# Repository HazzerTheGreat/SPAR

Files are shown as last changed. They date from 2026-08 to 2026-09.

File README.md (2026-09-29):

# SPAR

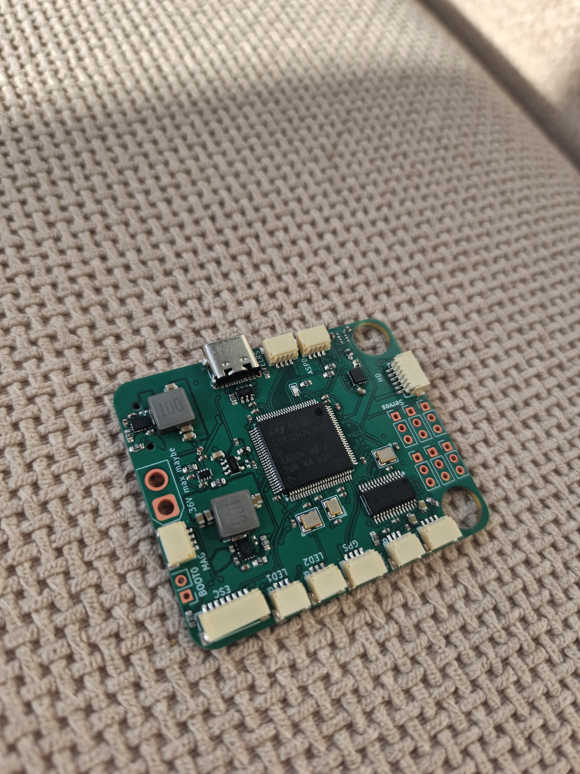
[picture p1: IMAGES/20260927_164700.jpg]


This is a flight controller primarily designed for fixed wing aircraft (or quadcopters etc) that is designed to 
run either BetaFlight, INAV or ArduPilot firmware. It handles flight stabilization, OSD, control of servos, waypoints,
data logging and anything else any other flight controller can do. This flight controller has an STM32H743 which is 
an extremely capable MCU with a blazing fast speed of up to 480MHz. Most likely overkill for the majority of applications
but it can accomodate for the most demanding projects. I made it as I was interested in the design of such systems
and also enjoy building aircraft and could find a highly capable flight controller useful plus the benefit that I have
built it myself.

**Specs:**

- ICM-42688-P for peak performance and high resolution positional sensing
- STM32H743 for processing whatever you need
- 5V and 9V buck converters for handling high power peripherals
- Micro SD card for black box logging
- 4 in 1 ESC support with DSHOT
- 6 other PWM outputs
- Analog OSD through AT7456E
- Support for external magnetometer, airspeed sensor and GPS
- BMP280 barometer for altitude measurements

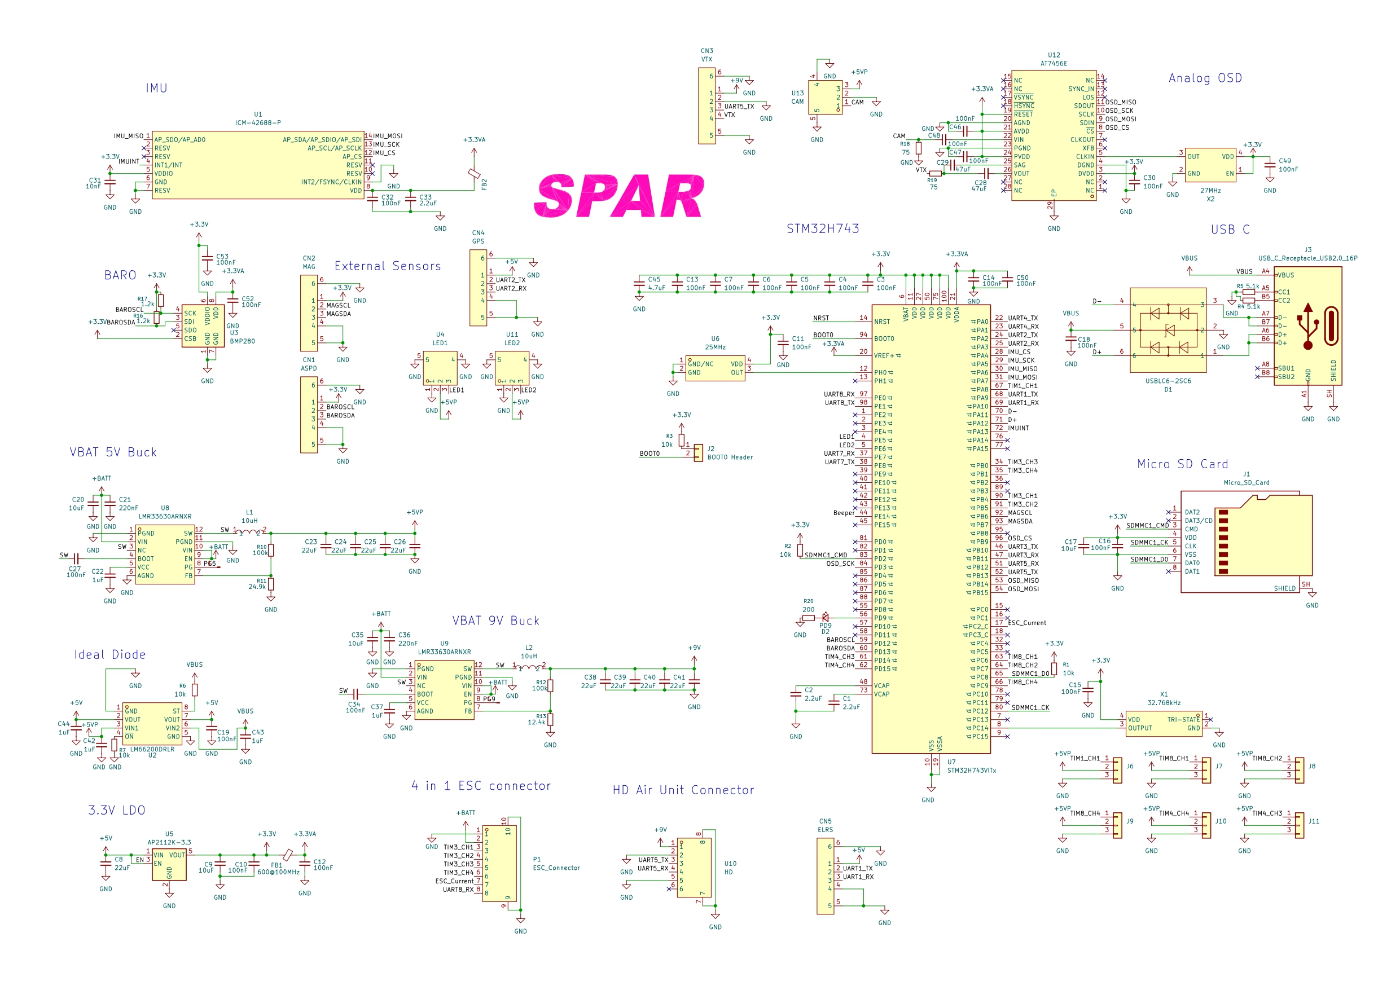
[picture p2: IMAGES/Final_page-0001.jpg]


**Peripherals:**

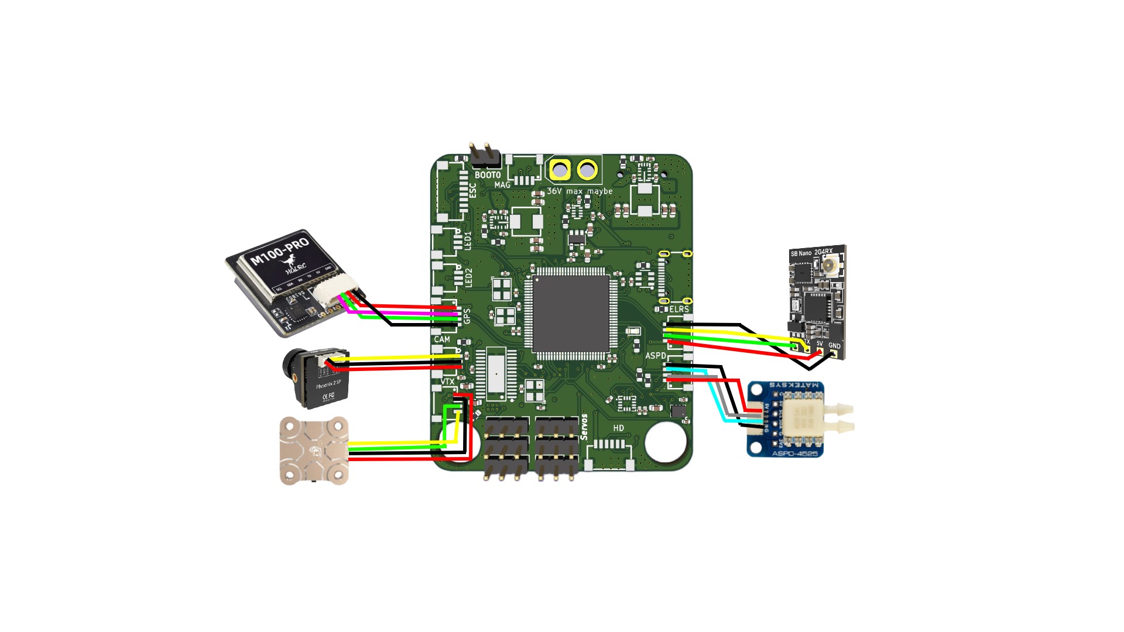
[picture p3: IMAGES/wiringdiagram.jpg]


The flight controller board has connectors for external airspeed, GPS, and mag sensors as well as plugs for ELRS, 4 in 1 ESC, analog camera, analog VTX, digital VTX and PWM LEDs.

**Firmware/flashing:**

This board does not have custom firmware, it is based on INAV: https://github.com/iNavFlight/inav/.
However a custom build of INAV including relevant target configuration is required.
I will put this custom target in the /Project_Files/INAV folder. This tutorial shows how to build INAV with a custom target: https://youtu.be/ThrsS_y9zDo?si=cllAaaTRHZ6ADbW4
To flash the board, the board must be powered up with the boot0 pin shorted to enter DFU mode on the STM32 where it can then be flashed in INAV configurator.

**BOM:**

The board costs about £27 from JLCPCB for a basic 6 layer PCB. The BOM for components can be found in the BOM.csv in the production folder. This totals around £40 which mainly
accounts for buying large quantities of passives so the per board price is probably much cheaper.

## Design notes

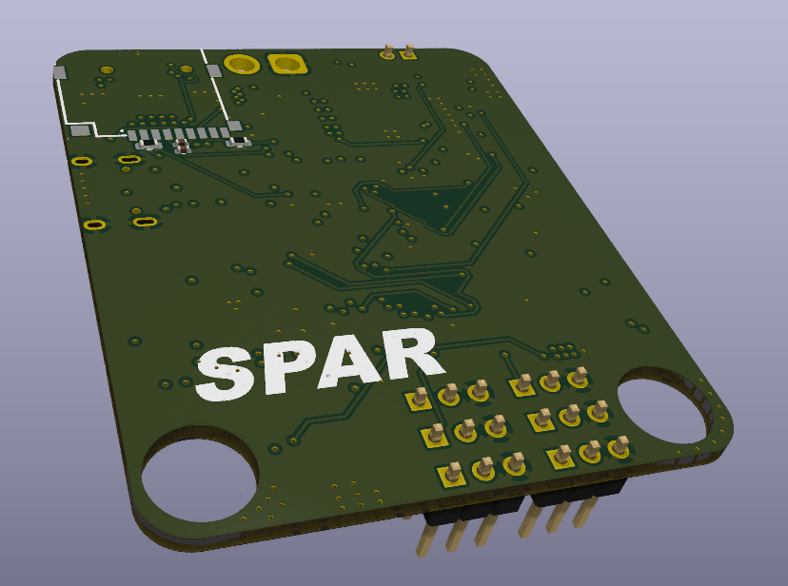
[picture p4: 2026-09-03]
IMAGES/pcb7.png

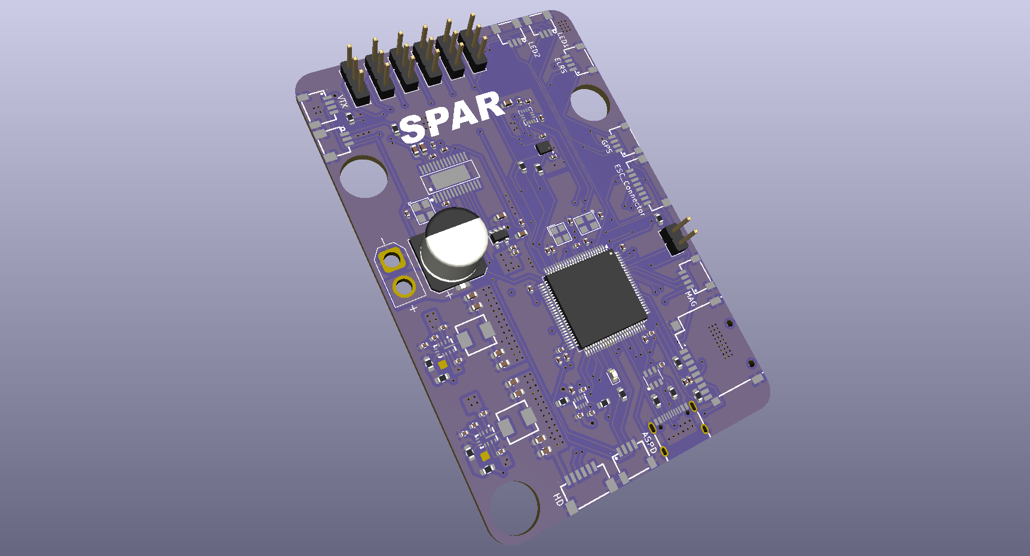
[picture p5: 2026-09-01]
IMAGES/FlightController.png

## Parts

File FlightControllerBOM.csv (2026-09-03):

Reference | Qty | Value | DNP | Exclude from BOM | Exclude from Board | Exclude from Simulation | Exclude from Position Files | Footprint | Datasheet | Price (minimum order):
C1,C2,C33 | 3 | 2.2uF |  |  |  |  | ${EXCLUDE_FROM_POS_FILES} | Capacitor_SMD:C_0402_1005Metric |  |  | 0.45
C3,C4,C5,C6,C7,C10,C11,C12,C13,C14,C15,C16,C18,C19,C27,C30,C32,C34,C46,C47,C48,C49,C50,C52,C53 | 25 | 100nF |  |  |  |  | ${EXCLUDE_FROM_POS_FILES} | Capacitor_SMD:C_0402_1005Metric |  |  | 0.45
C8,C23,C24,C25,C26,C38,C39,C40,C41 | 9 | 22uF |  |  |  |  | ${EXCLUDE_FROM_POS_FILES} | Capacitor_SMD:C_0603_1608Metric |  |  | 0.45
C9,C17,C20,C35 | 4 | 10uF |  |  |  |  | ${EXCLUDE_FROM_POS_FILES} | Capacitor_SMD:C_0402_1005Metric |  |  | 0.45
C21,C36 | 2 | 220nF |  |  |  |  | ${EXCLUDE_FROM_POS_FILES} | Capacitor_SMD:C_0402_1005Metric |  |  | 0.45
C22,C37,C42,C43,C44 | 5 | 1uF |  |  |  |  | ${EXCLUDE_FROM_POS_FILES} | Capacitor_SMD:C_0402_1005Metric |  |  | 0.45
C28,C29 | 2 | 47uF |  |  |  |  | ${EXCLUDE_FROM_POS_FILES} | Capacitor_SMD:C_0603_1608Metric |  |  | 0.97
C31 | 1 | 10nF |  |  |  |  | ${EXCLUDE_FROM_POS_FILES} | Capacitor_SMD:C_0402_1005Metric |  |  | 0.45
C45 | 1 | 4.7uF |  |  |  |  | ${EXCLUDE_FROM_POS_FILES} | Capacitor_SMD:C_0402_1005Metric |  |  | 0.45
CN1 | 1 | ASPD |  |  |  |  | ${EXCLUDE_FROM_POS_FILES} | easyeda2kicad:CONN-SMD_4P-P1.00_SM04B-SRSS-TB-LF-SN | https://lcsc.com/product-detail/Others_JST-Sales-America__JST-Sales-America-SM04B-SRSS-TB-LF-SN_C160404.html |  | 0.18
CN2 | 1 | MAG |  |  |  |  | ${EXCLUDE_FROM_POS_FILES} | easyeda2kicad:CONN-SMD_4P-P1.00_SM04B-SRSS-TB-LF-SN | https://lcsc.com/product-detail/Others_JST-Sales-America__JST-Sales-America-SM04B-SRSS-TB-LF-SN_C160404.html |  | 0.19
CN3 | 1 | VTX |  |  |  |  | ${EXCLUDE_FROM_POS_FILES} | easyeda2kicad:CONN-SMD_4P-P1.00_SM04B-SRSS-TB-LF-SN | https://lcsc.com/product-detail/Others_JST-Sales-America__JST-Sales-America-SM04B-SRSS-TB-LF-SN_C160404.html |  | 0.18
CN4 | 1 | GPS |  |  |  |  | ${EXCLUDE_FROM_POS_FILES} | easyeda2kicad:CONN-SMD_4P-P1.00_SM04B-SRSS-TB-LF-SN | https://lcsc.com/product-detail/Others_JST-Sales-America__JST-Sales-America-SM04B-SRSS-TB-LF-SN_C160404.html |  | 0.18
CN5 | 1 | ELRS |  |  |  |  | ${EXCLUDE_FROM_POS_FILES} | easyeda2kicad:CONN-SMD_4P-P1.00_SM04B-SRSS-TB-LF-SN | https://lcsc.com/product-detail/Others_JST-Sales-America__JST-Sales-America-SM04B-SRSS-TB-LF-SN_C160404.html |  | 0.18
D1 | 1 | USBLC6-2SC6 |  |  |  |  | ${EXCLUDE_FROM_POS_FILES} | easyeda2kicad:SOT-23-6_L2.9-W1.6-P0.95-LS2.8-BL | https://lcsc.com/product-detail/Diodes-ESD_STMicroelectronics_USBLC6-2SC6_USBLC6-2SC6_C7519.html |  | 0.82
D2 | 1 | PD9 |  |  |  |  | ${EXCLUDE_FROM_POS_FILES} | LED_SMD:LED_0603_1608Metric |  |  | 0.78
FB1,FB2 | 2 | 600@100MHz |  |  |  |  | ${EXCLUDE_FROM_POS_FILES} | Capacitor_SMD:C_0603_1608Metric |  |  | 0.79
J1 | 1 | Micro_SD_Card |  |  |  |  | ${EXCLUDE_FROM_POS_FILES} | easyeda2kicad:TF-SMD_TF-PUSH | https://www.we-online.com/components/products/datasheet/693072010801.pdf |  | 0.56
J2 | 1 | BOOT0 Header |  |  |  |  | ${EXCLUDE_FROM_POS_FILES} | Connector_PinHeader_2.54mm:PinHeader_1x02_P2.54mm_Vertical |  |  | 0.12
J3 | 1 | USB_C_Receptacle_USB2.0_16P |  |  |  |  | ${EXCLUDE_FROM_POS_FILES} | easyeda2kicad:USB-C-SMD_TYPE-C-16PIN-2MD-073 | https://www.usb.org/sites/default/files/documents/usb_type-c.zip |  | 1.27
J4,J5 | 2 | Conn_01x01_Pin |  |  |  |  | ${EXCLUDE_FROM_POS_FILES} |  |  |  | 0.2
J6,J7,J8,J9,J10,J11 | 6 | Conn_01x03 |  |  |  |  | ${EXCLUDE_FROM_POS_FILES} | Connector_PinHeader_2.54mm:PinHeader_1x03_P2.54mm_Vertical |  |  | 0.8
L1,L2 | 2 | 10uH |  |  |  |  | ${EXCLUDE_FROM_POS_FILES} | easyeda2kicad:IND-SMD_L5.2-W5.2_MCW-0530 | https://lcsc.com/product-detail/Power-Inductors_10uH-20_C181721.html |  | 0.7
P1 | 1 | ESC_Connector |  |  |  |  | ${EXCLUDE_FROM_POS_FILES} | easyeda2kicad:CONN-TH_SM08B-SRSS-TB-LF-SN | https://lcsc.com/product-detail/Others_JST-Sales-America__JST-Sales-America-SM08B-SRSS-TB-LF-SN_C160407.html |  | 0.55
R1,R2,R3,R6,R7 | 5 | 10k |  |  |  |  | ${EXCLUDE_FROM_POS_FILES} | Resistor_SMD:R_0603_1608Metric |  |  | 0.45
R4,R5 | 2 | 5.1k |  |  |  |  | ${EXCLUDE_FROM_POS_FILES} | Resistor_SMD:R_0603_1608Metric |  |  | 0.45
R10,R12 | 2 | 100k |  |  |  |  | ${EXCLUDE_FROM_POS_FILES} | Resistor_SMD:R_0603_1608Metric |  |  | 0.45
R11 | 1 | 24.9k |  |  |  |  | ${EXCLUDE_FROM_POS_FILES} | Resistor_SMD:R_0603_1608Metric |  |  | 0.45
R13 | 1 | 12.4k |  |  |  |  | ${EXCLUDE_FROM_POS_FILES} | Resistor_SMD:R_0603_1608Metric |  |  | 0.45
R16,R17 | 2 | 1.2k |  |  |  |  | ${EXCLUDE_FROM_POS_FILES} | Resistor_SMD:R_0603_1608Metric |  |  | 0.45
R18,R19 | 2 | 75 |  |  |  |  | ${EXCLUDE_FROM_POS_FILES} | Resistor_SMD:R_0603_1608Metric |  |  | 0.45
R20 | 1 | 200 |  |  |  |  | ${EXCLUDE_FROM_POS_FILES} | Resistor_SMD:R_0603_1608Metric |  |  | 0.45
U1 | 1 | ICM-42688-P |  |  |  |  | ${EXCLUDE_FROM_POS_FILES} | easyeda2kicad:LGA-14_L3.0-W2.5-P0.50-TL | https://www.lcsc.com/datasheet/C1850418.pdf |  | 6.29
U2 | 1 | LM66200DRLR |  |  |  |  | ${EXCLUDE_FROM_POS_FILES} | easyeda2kicad:SOT-583-8_L2.1-W1.2-P0.50-LS1.6-BL | https://www.lcsc.com/datasheet/C3235556.pdf |  | 0.53
U3 | 1 | BMP280 |  |  |  |  | ${EXCLUDE_FROM_POS_FILES} | Package_LGA:Bosch_LGA-8_2x2.5mm_P0.65mm_ClockwisePinNumbering | https://ae-bst.resource.bosch.com/media/_tech/media/datasheets/BST-BMP280-DS001.pdf |  | 1
U4 | 1 | LED1 |  |  |  |  | ${EXCLUDE_FROM_POS_FILES} | easyeda2kicad:CONN-SMD_SM03B-SRSS-TB-LF-SN-P | https://lcsc.com/product-detail/Others_JST-Sales-America__JST-Sales-America-SM03B-SRSS-TB-LF-SN-P_C160403.html |  | 0.33
U5 | 1 | AP2112K-3.3 |  |  |  |  | ${EXCLUDE_FROM_POS_FILES} | Package_TO_SOT_SMD:SOT-23-5 | https://www.diodes.com/assets/Datasheets/AP2112.pdf |  | 0.24
U6 | 1 | 25MHz |  |  |  |  | ${EXCLUDE_FROM_POS_FILES} | easyeda2kicad:OSC-SMD_4P-L2.5-W2.0-BL | https://www.lcsc.com/datasheet/C20623084.pdf |  | 0.52
U7 | 1 | STM32H743VITx |  |  |  |  | ${EXCLUDE_FROM_POS_FILES} | Package_QFP:LQFP-100_14x14mm_P0.5mm | https://www.st.com/resource/en/datasheet/stm32h743vi.pdf |  | 10.71
U8,U9 | 2 | LMR33630ARNXR |  |  |  |  | ${EXCLUDE_FROM_POS_FILES} | easyeda2kicad:VQFN-12_L3.0-W2.0-P0.65-BL_TI_RNX | https://www.lcsc.com/datasheet/C2861505.pdf |  | 3.64
U10 | 1 | HD |  |  |  |  | ${EXCLUDE_FROM_POS_FILES} | easyeda2kicad:CONN-SMD_SM06B-SRSS-TB-LF-SN | https://lcsc.com/product-detail/Others_JST-Sales-America__JST-Sales-America-SM06B-SRSS-TB-LF-SN_C160405.html |  | 0.7
U11 | 1 | LED2 |  |  |  |  | ${EXCLUDE_FROM_POS_FILES} | easyeda2kicad:CONN-SMD_SM03B-SRSS-TB-LF-SN-P | https://lcsc.com/product-detail/Others_JST-Sales-America__JST-Sales-America-SM03B-SRSS-TB-LF-SN-P_C160403.html |  | 0.6
U12 | 1 | AT7456E |  |  |  |  | ${EXCLUDE_FROM_POS_FILES} | easyeda2kicad:TSSOP-28_L9.7-W4.4-P0.65-LS6.4-BL-EP-2 | https://lcsc.com/product-detail/Analog-ICs_AT7456E_C82351.html |  | 3.32
U13 | 1 | CAM |  |  |  |  | ${EXCLUDE_FROM_POS_FILES} | easyeda2kicad:CONN-SMD_SM03B-SRSS-TB-LF-SN-P | https://lcsc.com/product-detail/Others_JST-Sales-America__JST-Sales-America-SM03B-SRSS-TB-LF-SN-P_C160403.html |  | 0.6
X1 | 1 | 32.768kHz |  |  |  |  | ${EXCLUDE_FROM_POS_FILES} | easyeda2kicad:OSC-SMD_4P-L3.2-W2.5-BL | https://www.lcsc.com/datasheet/C2901582.pdf |  | 0.55
X2 | 1 | 27MHz |  |  |  |  | ${EXCLUDE_FROM_POS_FILES} | easyeda2kicad:OSC-SMD_4P-L3.2-W2.5-BL | https://www.lcsc.com/datasheet/C2901577.pdf |  | 0.76

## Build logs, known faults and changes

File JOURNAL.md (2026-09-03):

---
title: "SPAR"
author: "HarryM"
description: ""
created_at: "2026-08-13"
---

# 13th of August: Hardware selection and research

In terms of hardware, I made the following selections:

- STM32H743 for the main microcontroller as it is well documented within BetaFlight and INAV (the chosen flight control software).
It also has plenty of performance running at 480MHz and has a large variety of peripherals available which is useful for flight control.

- For flash memory for flight logs I initially chose the W25N02KVZEIR from winbond. However I think it is overkill for this and I will
instead use a micro SD card slot to keep cost and unnecessary complexity down.

- For sensors I went with the ICM-42688-P for the IMU as it is the preferred choice for BF hardware (which I am referencing), the BMP280
for pressure sensing as it again is preferred and is the standard in most off-the-shelf solutions. Finally, I went for the LIS3MDL for 
magnetic field sensing to produce a compass heading.

- For the power supply setup I decided on the AP2112K for the 3.3V rail as that is only going to pull at most 400mA while the AP2112K can
handle 600mA continuous. I decided to go for the AP1509-50SG-13 for the 5V rail as it can provide 2A which will be necessary for servos,
lights ETC when not using a BEC output from the ESC

MCU_Selection

**Total Time Spent: 2 hours**

# 14th of August: STM32 schematic setup

I spent some time drawing up the base schematic for the STM32H743 microcontroller setting up all the required components such as: 

- Power Input and decoupling
- 25mHz oscillator
- 32.768kHz oscillator for RTC
- SD card slot for black box logging in SDMMC 1 bit mode for simplicity
- BOOT0 connecter for entering DFU mode

Schematic_block

Next I will add the peripherals and sort out UARTs as per betaflight's recommendation and then I will think about some extra features
that will make it stand out

**Total Time Spent: 2 hours**

# 14th of August: Planned out pin functions using cubeMX

I needed to plan out which pins I was going to use for the various UARTS and peripherals while making sure they did not clash. CubeMX files
will not be needed by INAV or BetaFlight but it is very useful in planning. I have not allocated misc pins such as beeper or lights as that
can be any GPIO pin

Schematic_block

**Total Time Spent: 1 hour**

# 15th of August: Power setup and pin mapping

I mapped the pins in the schematic to their various functions including all the UARTS and I2C and SPI which I will wire up to the sensors
soon. I also added a USB C port with proper ESD protection and I added a 5V buck to convert the battery voltage into the 5V used by the 
peripherals and LDO for the MCU. I then added a 2 channel ideal diode to handle switching between USB 5V and the 5V coming from the battery
buck. Might have made some mistakes so will check through.

Schematic_block

**Total Time Spent: 2 hours**

# 15th of August: Sensor Setup and 9V buck

I wired up the 3 sensors with SPI and I2C. I also added a 9V buck to step down VBAT to 9V for a HD VTX such as a DJI O3 or runcam wifilink.
I also corrected an error with my buck converter where feedback node was connected before inductor and not after.

Schematic_block

**Total Time Spent: 1 hour**

# 30th of August: Sensor changes and OSD

Due to being extremely sensitive to interference, I have decided to remove the magnetometer and instead add the option to add one externally
and have also added the option for an airspeed sensor on the same I2C bus as the barometer. I have now added an analog OSD using the AT7456E
due to its price and availability as I wanted it to be analog friendly and added the corresponding JST connectors for the VTX and camera.

Schematic_block

**Total Time Spent: 1.5 hours**

# 31st of August: Finalizing schematic and layout setup

I finalized the schematic and corrected some small errors here and there. I began the layout with the STM32H7 and it's various passives and
the oscillator. I then setup the 5V and 9V buck converters based on TI's reference layout guide making sure to be mindful of where different
power planes will be. I then planned the layout of the board and will soon move components into place and begin to route.

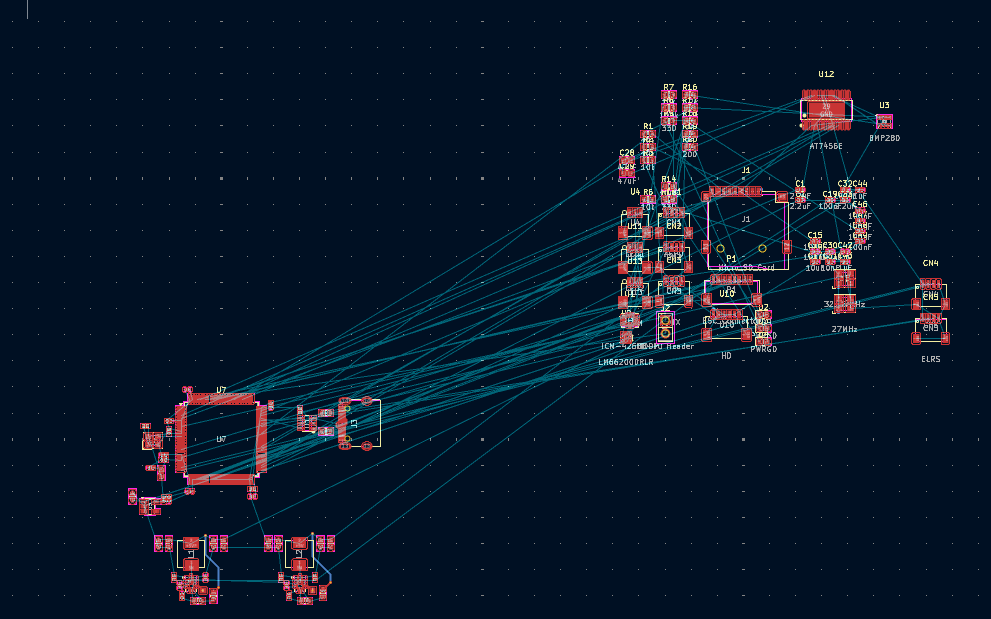
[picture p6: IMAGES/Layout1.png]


**Total Time Spent: 2 hours**

# 1st of September: PCB layout progress

I spent some time making progress on the PCB layout and planning the dimensions of the board. The form factor is a bit larger than most other 
fixed wing FC's but that is due to it being all on one board (power management, FC etc).

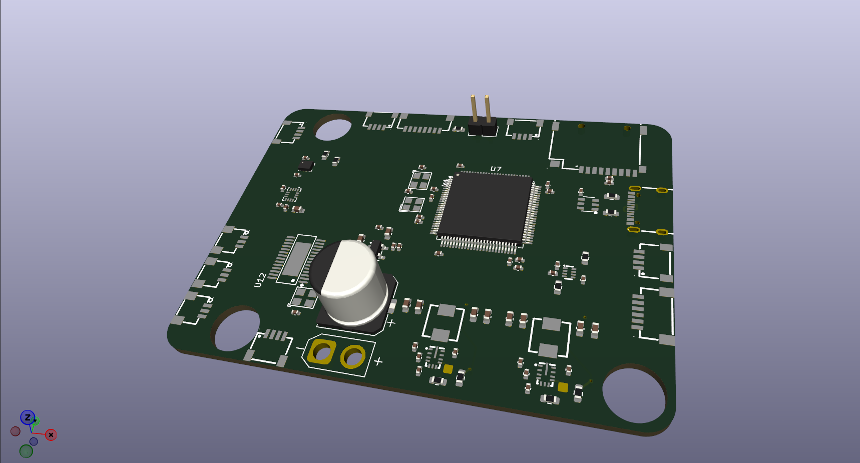
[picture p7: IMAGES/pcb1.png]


**Total Time Spent: 1 hour**

# 1st of September: Power layout

I finished laying out all the components and I added the inner ground plane and power rails for ease of layout. I made a ground moat around the 
highly sensitive sensors and fed them through a filtered 3.3V power to remove unwanted noise and provide a clean output.

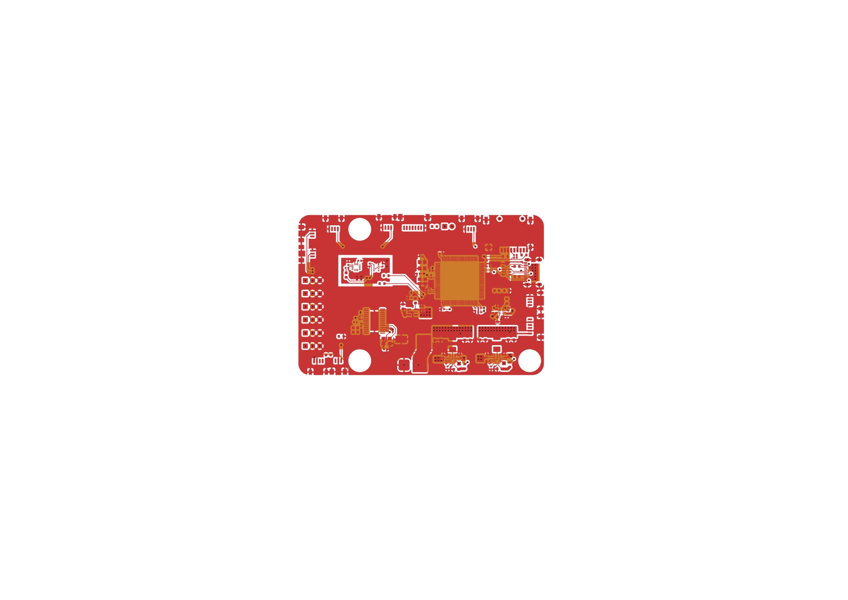
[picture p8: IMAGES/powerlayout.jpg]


**Total Time Spent: 2 hours**

# 1st of September: Main Routing

I finished off some routing using a priority of high speed and analog signals first and power rails and worked down to UARTs and PWMs. Some more
routing is needed but then the board should be complete.

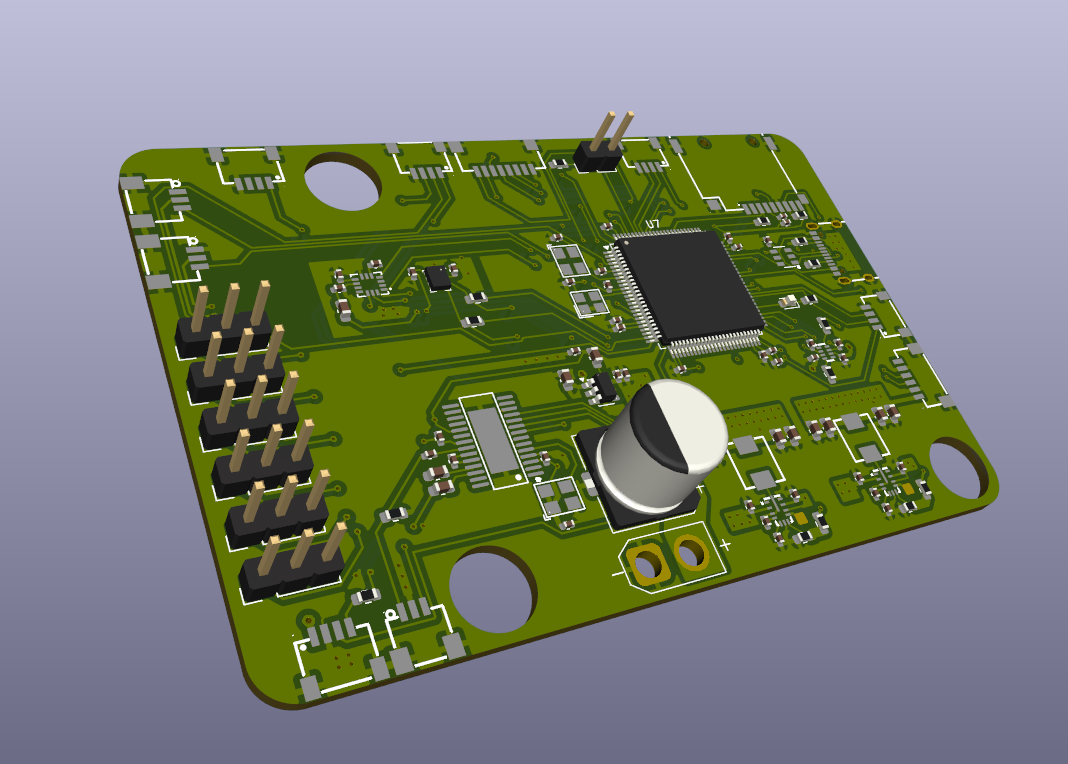
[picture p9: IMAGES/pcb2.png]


**Total Time Spent: 1 hour**

# 2nd of September: A new look

After some consideration I decided to redo the board design, layout and routing, pretty much just starting the PCB from scratch. This was for a couple
of reasons:

- V1 was too big
- The power planes were split in several places which somewhat defeated their purpose
- Signals were here there and everywhere (traces too long)
- Poor component placement

So I started from scratch on the layout and drew up on paper where the optimal location for each component was in terms of routing to the STM32H7, power
access, and importantly for the analog component - EMI. I have layed out most components (not all passives done yet) and set up the power rails. The board
is now much more compact and dense at 48mm x 58mm. While this may seem like backtracking on my issues, I have switched to a 6 layer PCB with a stackup of
Mixed - Ground - Signal - Power - Ground - Mixed. This is common for boards of this complexity and size and has really made the layout so much easier. I 
will slowly work to get the layout finished and then after that it is time for manufacturing.

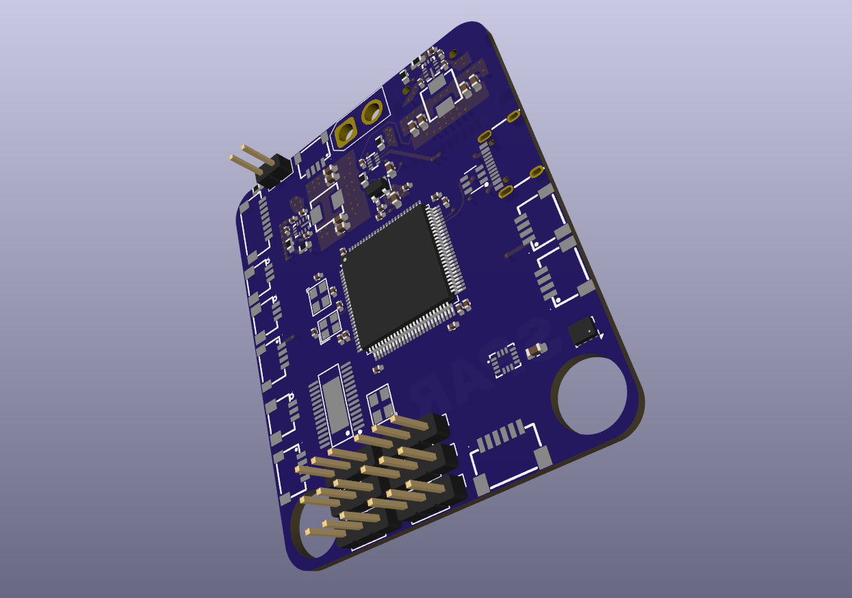
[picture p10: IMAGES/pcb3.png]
New_Design


**Total Time Spent: 2 hours**

# 2nd of September: Complete (I hope)

I feel much better about this board after I shifted course and redesigned the layout completely. I spent the last couple of hours routing signals, power,
doing fills etc. The board is now in a complete/awaiting any minor tweaks or finishing touches. I think I will add some more silkscreen text on different
parts of the board but apart from that I hope that there is nothing else to do.

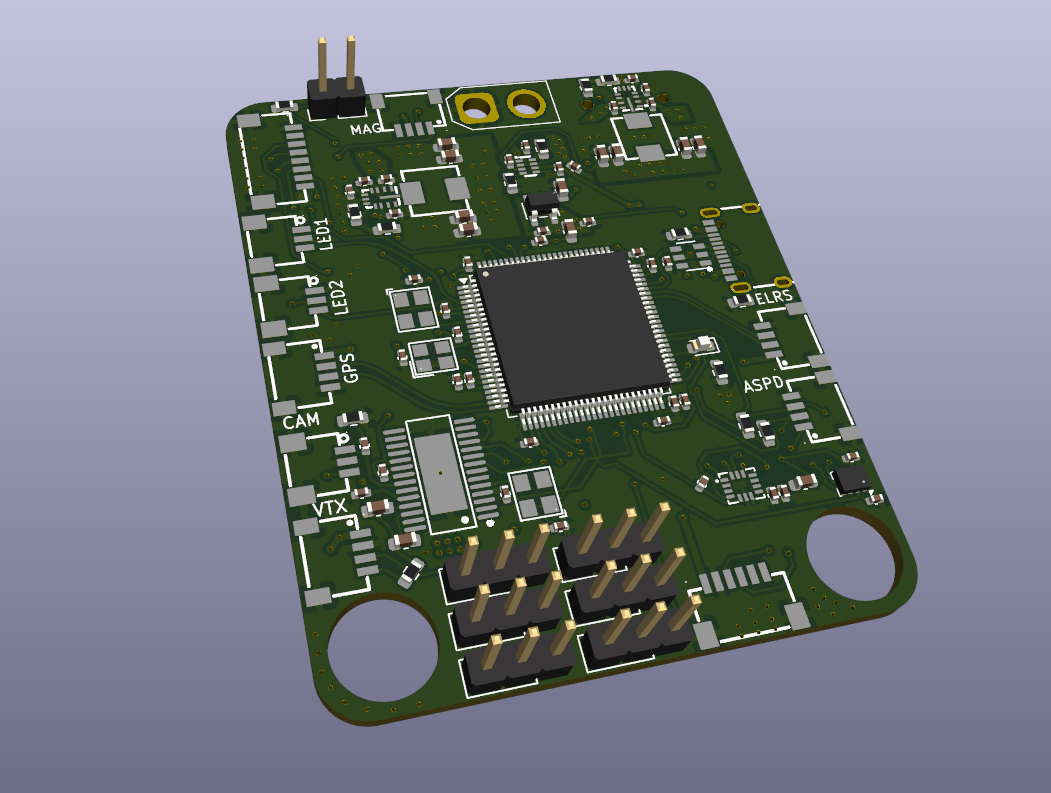
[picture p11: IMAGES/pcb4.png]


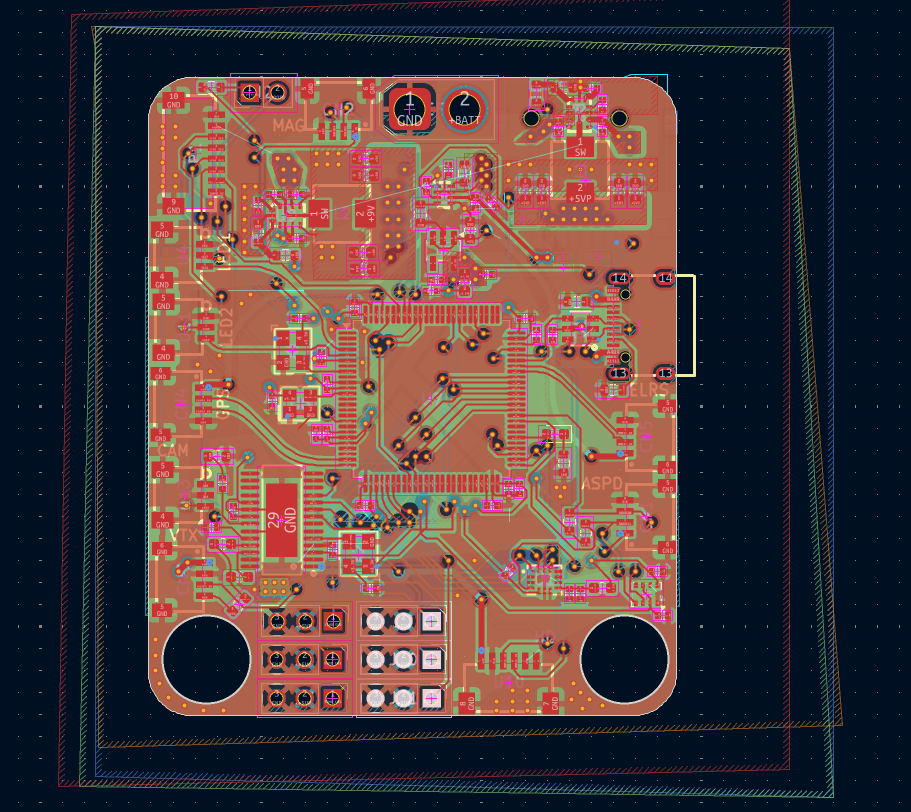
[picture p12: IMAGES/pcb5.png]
Finished_schematic


**Total Time Spent: 2 hours**

# 3rd of September: Finishing touches

I was right and there were some issues to iron out but I now think that has all been done.

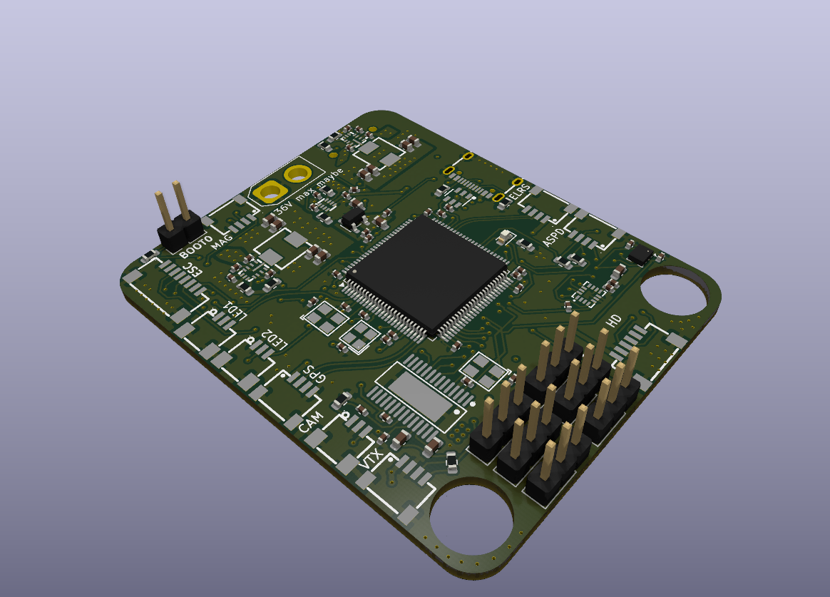
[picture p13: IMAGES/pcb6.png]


**Total Time Spent: 1 hour**

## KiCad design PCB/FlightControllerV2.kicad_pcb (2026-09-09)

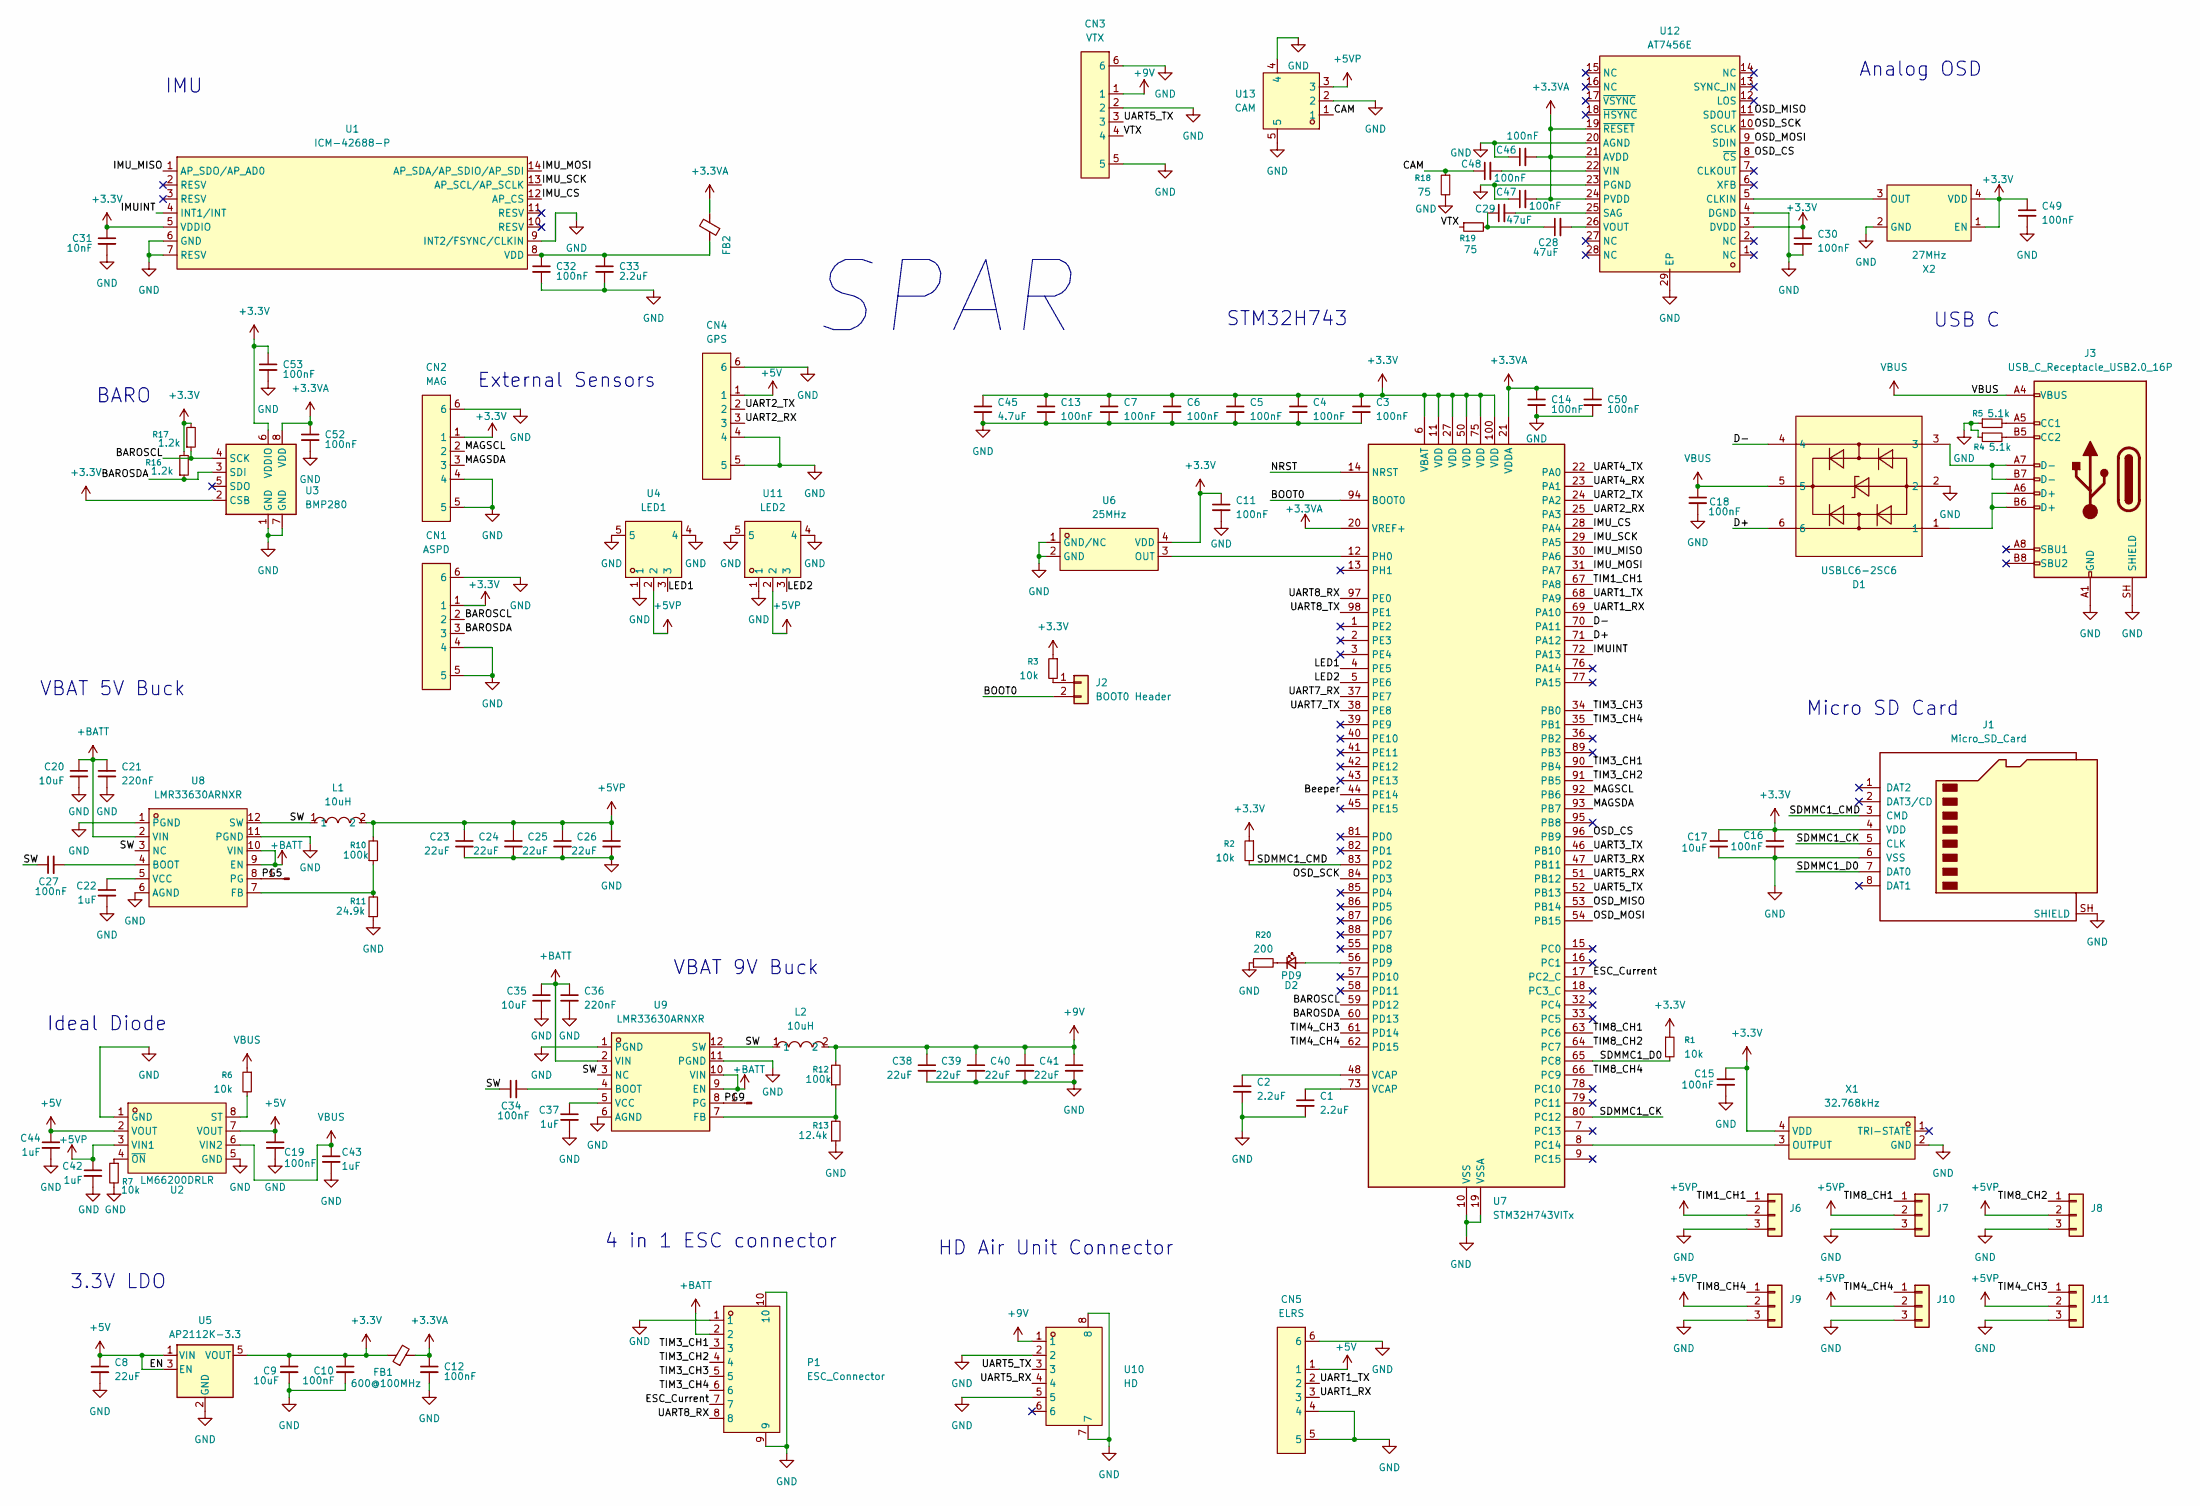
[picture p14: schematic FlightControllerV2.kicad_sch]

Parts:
C1, C2, C33: 2.2uF; C_0402_1005Metric
C3, C4, C5, C6, C7, C10, C11, C12, C13, C14, C15, C16, C18, C19, C27, C30, C32, C34, C46, C47, C48, C49, C50, C52, C53: 100nF; C_0402_1005Metric
C8, C23, C24, C25, C26, C38, C39, C40, C41: 22uF; C_0603_1608Metric
C9, C17, C20, C35: 10uF; C_0402_1005Metric
C21, C36: 220nF; C_0402_1005Metric
C22, C37, C42, C43, C44: 1uF; C_0402_1005Metric
C28, C29: 47uF; C_0603_1608Metric
C31: 10nF; C_0402_1005Metric
C45: 4.7uF; C_0402_1005Metric
CN1: ASPD; CONN-SMD_4P-P1.00_SM04B-SRSS-TB-LF-SN; MPN SM04B-SRSS-TB(LF)(SN); LCSC Part C160404
CN2: MAG; CONN-SMD_4P-P1.00_SM04B-SRSS-TB-LF-SN; MPN SM04B-SRSS-TB(LF)(SN); LCSC Part C160404
CN3: VTX; CONN-SMD_4P-P1.00_SM04B-SRSS-TB-LF-SN; MPN SM04B-SRSS-TB(LF)(SN); LCSC Part C160404
CN4: GPS; CONN-SMD_4P-P1.00_SM04B-SRSS-TB-LF-SN; MPN SM04B-SRSS-TB(LF)(SN); LCSC Part C160404
CN5: ELRS; CONN-SMD_4P-P1.00_SM04B-SRSS-TB-LF-SN; MPN SM04B-SRSS-TB(LF)(SN); LCSC Part C160404
D1: USBLC6-2SC6; SOT-23-6_L2.9-W1.6-P0.95-LS2.8-BL; MPN USBLC6-2SC6; LCSC Part C7519
D2: PD9; LED_0603_1608Metric
FB1, FB2: 600@100MHz; C_0603_1608Metric
J1: Micro_SD_Card; TF-SMD_TF-PUSH
J2: BOOT0 Header; PinHeader_1x02_P2.54mm_Vertical
J3: USB_C_Receptacle_USB2.0_16P; USB-C-SMD_TYPE-C-16PIN-2MD-073
J4, J5: Conn_01x01_Pin
J6, J7, J8, J9, J10, J11: Conn_01x03; PinHeader_1x03_P2.54mm_Vertical
L1, L2: 10uH; IND-SMD_L5.2-W5.2_MCW-0530; MPN SMMS0530-100M; LCSC Part C181721
P1: ESC_Connector; CONN-TH_SM08B-SRSS-TB-LF-SN; MPN SM08B-SRSS-TB(LF)(SN); LCSC Part C160407
R1, R2, R3, R6, R7: 10k; R_0603_1608Metric
R4, R5: 5.1k; R_0603_1608Metric
R10, R12: 100k; R_0603_1608Metric
R11: 24.9k; R_0603_1608Metric
R13: 12.4k; R_0603_1608Metric
R16, R17: 1.2k; R_0603_1608Metric
R18, R19: 75; R_0603_1608Metric
R20: 200; R_0603_1608Metric
U1: ICM-42688-P; LGA-14_L3.0-W2.5-P0.50-TL; MPN ICM-42688-P; LCSC Part C1850418
U2: LM66200DRLR; SOT-583-8_L2.1-W1.2-P0.50-LS1.6-BL; MPN LM66200DRLR; LCSC Part C3235556
U3: BMP280; Bosch_LGA-8_2x2.5mm_P0.65mm_ClockwisePinNumbering
U4: LED1; CONN-SMD_SM03B-SRSS-TB-LF-SN-P; MPN SM03B-SRSS-TB(LF)(SN); LCSC Part C160403
U5: AP2112K-3.3; SOT-23-5
U6: 25MHz; OSC-SMD_4P-L2.5-W2.0-BL; MPN 8122S-25.000NQ33FTL; LCSC Part C20623084
U7: STM32H743VITx; LQFP-100_14x14mm_P0.5mm
U8, U9: LMR33630ARNXR; VQFN-12_L3.0-W2.0-P0.65-BL_TI_RNX; MPN LMR33630ARNXR; LCSC Part C2861505
U10: HD; CONN-SMD_SM06B-SRSS-TB-LF-SN; MPN SM06B-SRSS-TB(LF)(SN); LCSC Part C160405
U11: LED2; CONN-SMD_SM03B-SRSS-TB-LF-SN-P; MPN SM03B-SRSS-TB(LF)(SN); LCSC Part C160403
U12: AT7456E; TSSOP-28_L9.7-W4.4-P0.65-LS6.4-BL-EP-2; MPN AT7456E; LCSC Part C82351
U13: CAM; CONN-SMD_SM03B-SRSS-TB-LF-SN-P; MPN SM03B-SRSS-TB(LF)(SN); LCSC Part C160403
X1: 32.768kHz; OSC-SMD_4P-L3.2-W2.5-BL; MPN SX3M32.768KM20F30TNN; LCSC Part C2901582
X2: 27MHz; OSC-SMD_4P-L3.2-W2.5-BL; MPN SX3M27.000M20F30TNN; LCSC Part C2901577

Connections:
+3.3V: C3.1, C4.1, C5.1, C6.1, C7.1, C9.1, C10.1, C11.1, C13.1, C15.1, C16.1, C17.1, C30.1, C31.1, C45.1, C49.1, C53.1, CN1.1, CN2.1, FB1.1, J1.4 (VDD), R1.1, R2.1, R3.1, R16.2, R17.2, U1.5 (VDDIO), U3.2 (CSB), U3.6 (VDDIO), U5.5 (VOUT), U6.4 (VDD), U7.6 (VBAT), U7.11 (VDD), U7.27 (VDD), U7.50 (VDD), U7.75 (VDD), U7.100 (VDD), U12.3 (DVDD), X1.4 (VDD), X2.1 (EN), X2.4 (VDD)
+3.3VA: C12.1, C14.1, C46.2, C47.2, C50.1, C52.1, FB1.2, FB2.2, U3.8 (VDD), U7.20 (VREF+), U7.21 (VDDA), U12.19 (~RESET), U12.21 (AVDD), U12.24 (PVDD)
+5V: C8.1, C19.1, C44.1, CN4.1, CN5.1, U2.2 (VOUT), U2.7 (VOUT), U5.1 (VIN), U5.3 (EN)
+5VP: C23.1, C24.1, C25.1, C26.1, C42.1, J6.2, J7.2, J8.2, J9.2, J10.2, J11.2, L1.2, R10.2, U2.3 (VIN1), U4.2, U11.2, U13.3
+9V: C38.1, C39.1, C40.1, C41.1, CN3.1, L2.2, R12.2, U10.1
+BATT: C20.1, C21.1, C35.1, C36.1, P1.2, U8.2 (VIN), U8.9 (EN), U8.10 (VIN), U9.2 (VIN), U9.9 (EN), U9.10 (VIN)
/BAROSCL: CN1.2, R17.1, U3.4 (SCK), U7.59 (PD12)
/BAROSDA: CN1.3, R16.1, U3.3 (SDI), U7.60 (PD13)
/BOOT0: J2.2, U7.94 (BOOT0)
/Beeper: U7.44 (PE14)
/CAM: C48.1, R18.1, U13.1
/D+: D1.6, U7.71 (PA12)
/D-: D1.4, U7.70 (PA11)
/ESC_Current: P1.7, U7.17 (PC2_C)
/IMUINT: U1.4 (INT1/INT), U7.72 (PA13)
/IMU_CS: U1.12 (AP_CS), U7.28 (PA4)
/IMU_MISO: U1.1 (AP_SDO/AP_AD0), U7.30 (PA6)
/IMU_MOSI: U1.14 (AP_SDA/AP_SDIO/AP_SDI), U7.31 (PA7)
/IMU_SCK: U1.13 (AP_SCL/AP_SCLK), U7.29 (PA5)
/LED1: U4.3, U7.4 (PE5)
/LED2: U7.5 (PE6), U11.3
/MAGSCL: CN2.2, U7.92 (PB6)
/MAGSDA: CN2.3, U7.93 (PB7)
/NRST: U7.14 (NRST)
/OSD_CS: U7.96 (PB9), U12.8 (~CS)
/OSD_MISO: U7.53 (PB14), U12.11 (SDOUT)
/OSD_MOSI: U7.54 (PB15), U12.9 (SDIN)
/OSD_SCK: U7.84 (PD3), U12.10 (SCLK)
/PG5: J4.1, U8.8 (PG)
/PG9: J5.1, U9.8 (PG)
/SDMMC1_CK: J1.5 (CLK), U7.80 (PC12)
/SDMMC1_CMD: J1.3 (CMD), R2.2, U7.83 (PD2)
/SDMMC1_D0: J1.7 (DAT0), R1.2, U7.65 (PC8)
/SW: C27.1, C34.1, L1.1, L2.1, U8.3 (NC), U8.12 (SW), U9.3 (NC), U9.12 (SW)
/TIM1_CH1: J6.1, U7.67 (PA8)
/TIM3_CH1: P1.3, U7.90 (PB4)
/TIM3_CH2: P1.4, U7.91 (PB5)
/TIM3_CH3: P1.5, U7.34 (PB0)
/TIM3_CH4: P1.6, U7.35 (PB1)
/TIM4_CH3: J11.1, U7.61 (PD14)
/TIM4_CH4: J10.1, U7.62 (PD15)
/TIM8_CH1: J7.1, U7.63 (PC6)
/TIM8_CH2: J8.1, U7.64 (PC7)
/TIM8_CH4: J9.1, U7.66 (PC9)
/UART1_RX: CN5.3, U7.69 (PA10)
/UART1_TX: CN5.2, U7.68 (PA9)
/UART2_RX: CN4.3, U7.25 (PA3)
/UART2_TX: CN4.2, U7.24 (PA2)
/UART3_RX: U7.47 (PB11)
/UART3_TX: U7.46 (PB10)
/UART4_RX: U7.23 (PA1)
/UART4_TX: U7.22 (PA0)
/UART5_RX: U7.51 (PB12), U10.4
/UART5_TX: CN3.3, U7.52 (PB13), U10.3
/UART7_RX: U7.37 (PE7)
/UART7_TX: U7.38 (PE8)
/UART8_RX: P1.8, U7.97 (PE0)
/UART8_TX: U7.98 (PE1)
/VTX: CN3.4, R19.1
GND: C1.2, C2.2, C3.2, C4.2, C5.2, C6.2, C7.2, C8.2, C9.2, C10.2, C11.2, C12.2, C13.2, C14.2, C15.2, C16.2, C17.2, C18.2, C19.2, C20.2, C21.2, C22.2, C23.2, C24.2, C25.2, C26.2, C30.2, C31.2, C32.2, C33.2, C35.2, C36.2, C37.2, C38.2, C39.2, C40.2, C41.2, C42.2, C43.2, C44.2, C45.2, C46.1, C47.1, C49.2, C50.2, C52.2, C53.2, CN1.4, CN1.5, CN1.6, CN2.4, CN2.5, CN2.6, CN3.2, CN3.5, CN3.6, CN4.4, CN4.5, CN4.6, CN5.4, CN5.5, CN5.6, D1.2, J1.6 (VSS), J1.SH (SHIELD), J3.13, J3.14, J3.A1 (GND), J3.A1B12, J3.A12 (GND), J3.B1 (GND), J3.B1A12, J3.B12 (GND), J3.SH (SHIELD), J6.3, J7.3, J8.3, J9.3, J10.3, J11.3, P1.1, P1.9, P1.10, R4.1, R5.1, R7.2, R11.1, R13.1, R18.2, R20.1, U1.6 (GND), U1.7 (RESV), U1.9 (INT2/FSYNC/CLKIN), U2.1 (GND), U2.5 (GND), U3.1 (GND), U3.7 (GND), U4.1, U4.4, U4.5, U5.2 (GND), U6.1 (GND/NC), U6.2 (GND), U7.10 (VSS), U7.19 (VSSA), U7.26 (VSS), U7.49 (VSS), U7.74 (VSS), U7.99 (VSS), U8.1 (PGND), U8.6 (AGND), U8.11 (PGND), U9.1 (PGND), U9.6 (AGND), U9.11 (PGND), U10.2, U10.5, U10.7, U10.8, U11.1, U11.4, U11.5, U12.4 (DGND), U12.20 (AGND), U12.23 (PGND), U12.29 (EP), U13.2, U13.4, U13.5, X1.2 (GND), X2.2 (GND)
unnamed: C1.1, U7.73 (VCAP)
unnamed: C2.1, U7.48 (VCAP)
unnamed: C28.1, C29.1, R19.2
unnamed: D1.1, J3.A6 (D+), J3.B6 (D+)
unnamed: D1.3, J3.A7 (D-), J3.B7 (D-)
unnamed: D2.2 (A), U7.56 (PD9)
unnamed: D2.1 (K), R20.2
unnamed: J2.1, R3.2
unnamed: J3.A5 (CC1), R5.2
unnamed: J3.B5 (CC2), R4.2
unnamed: C32.1, C33.1, FB2.1, U1.8 (VDD)
unnamed: R6.2, U2.8 (ST)
unnamed: R7.1, U2.4 (~ON)
unnamed: U6.3 (OUT), U7.12 (PH0)
unnamed: U7.8 (PC14), X1.3 (OUTPUT)
unnamed: C27.2, U8.4 (BOOT)
unnamed: R10.1, R11.2, U8.7 (FB)
unnamed: C22.1, U8.5 (VCC)
unnamed: C34.2, U9.4 (BOOT)
unnamed: R12.1, R13.2, U9.7 (FB)
unnamed: C37.1, U9.5 (VCC)
unnamed: U12.5 (CLKIN), X2.3 (OUT)
unnamed: C29.2, U12.25 (SAG)
unnamed: C48.2, U12.22 (VIN)
unnamed: C28.2, U12.26 (VOUT)
VBUS: C18.1, C43.1, D1.5, J3.A4 (VBUS), J3.A9 (VBUS), J3.B4 (VBUS), J3.B9 (VBUS), R6.1, U2.6 (VIN2)

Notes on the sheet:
External Sensors
Analog OSD
BARO
Ideal Diode
SPAR
VBAT 5V Buck
VBAT 9V Buck
Micro SD Card
4 in 1 ESC connector
IMU
3.3V LDO
STM32H743
USB C
HD Air Unit Connector

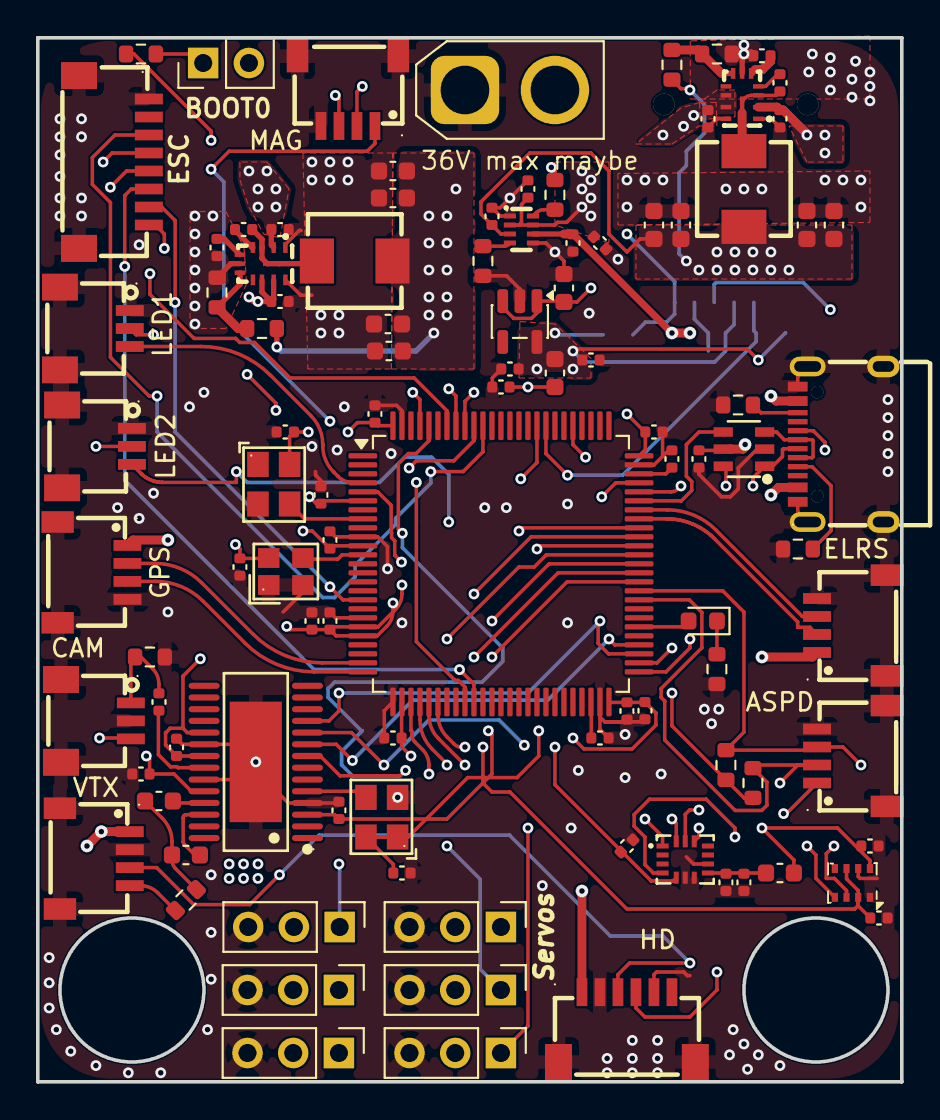
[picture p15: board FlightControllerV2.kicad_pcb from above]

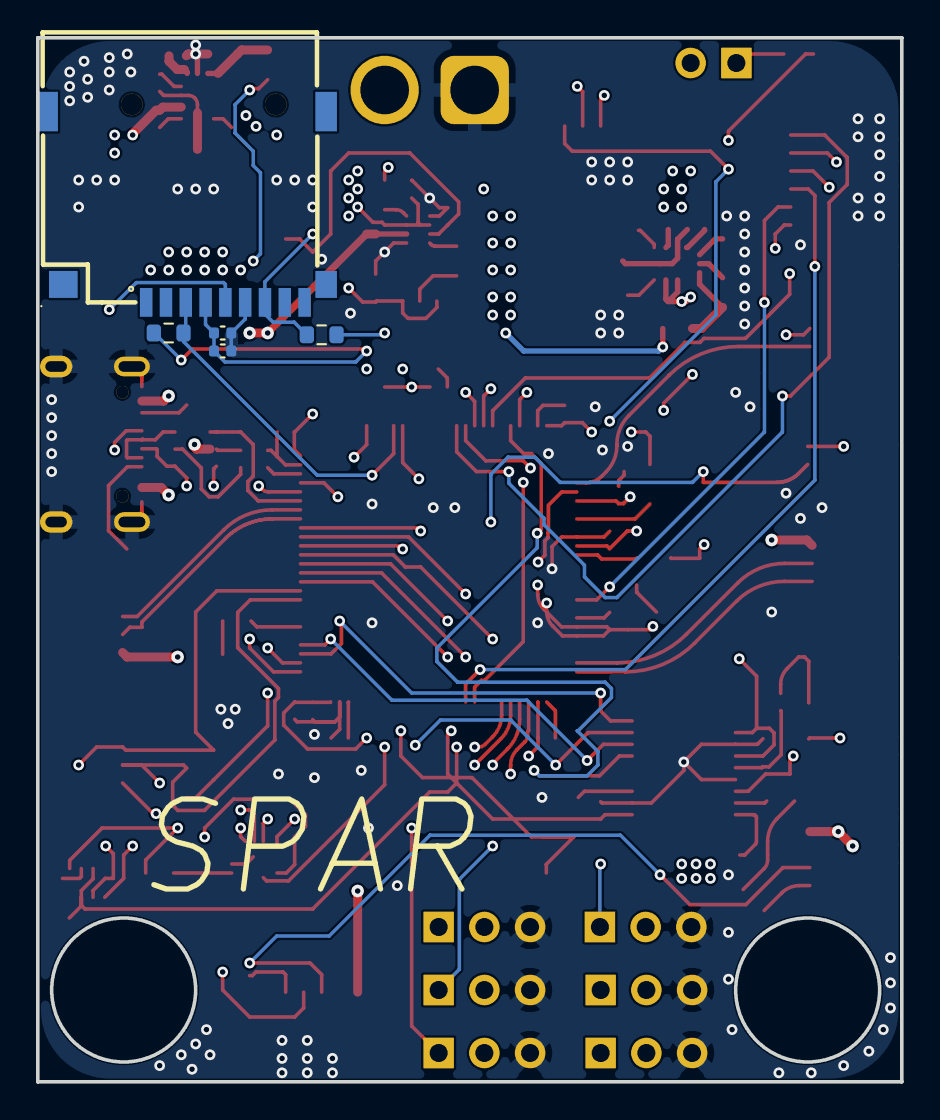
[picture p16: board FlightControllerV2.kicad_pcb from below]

Board: 6 copper layers, 48.0 x 58.0 mm, 104 parts (5 on the bottom side), 75 nets.

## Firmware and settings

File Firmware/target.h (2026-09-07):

/*
 * This file is part of INAV.
 *
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
 * You should have received a copy of the GNU General Public License
 * along with INAV.  If not, see <http://www.gnu.org/licenses/>.
 */


#pragma once

#define TARGET_BOARD_IDENTIFIER "H743"


#define USBD_PRODUCT_STRING     "SPARH743"


#define USE_TARGET_CONFIG

#define LED0                    PE5
#define LED1                    PE6


// *************** IMU generic ***********************
#define USE_TARGET_IMU_HARDWARE_DESCRIPTORS



// *************** SPI1 IMU0 MPU6000 ****************
#define USE_SPI
#define USE_SPI_DEVICE_1
#define SPI1_SCK_PIN            PA5
#define SPI1_MISO_PIN           PA6
#define SPI1_MOSI_PIN           PD7

#define USE_IMU_MPU6000

#define IMU_MPU6000_ALIGN       CW0_DEG_FLIP
#define MPU6000_SPI_BUS          BUS_SPI1
#define MPU6000_CS_PIN          PC15


// *************** SPI2 OSD ***********************
  #define USE_SPI_DEVICE_2
  #define SPI2_SCK_PIN            PB13
  #define SPI2_MISO_PIN           PB14
  #define SPI2_MOSI_PIN           PB15

#if defined(MATEKH743)
  #define USE_MAX7456
  #define MAX7456_SPI_BUS         BUS_SPI2
  #define MAX7456_CS_PIN          PB12
#endif

// *************** I2C /Baro/Mag *********************
#define USE_I2C
#define USE_I2C_DEVICE_1
#define I2C1_SCL                PB6
#define I2C1_SDA                PB7

#define USE_I2C_DEVICE_2
#define I2C2_SCL                PB10
#define I2C2_SDA                PB11

#define USE_BARO
#define BARO_I2C_BUS            BUS_I2C2
#define USE_BARO_BMP280
#define USE_BARO_MS5611
#define USE_BARO_DPS310
#define USE_BARO_SPL06

#define USE_MAG
#define MAG_I2C_BUS             BUS_I2C1
#define USE_MAG_ALL

#define TEMPERATURE_I2C_BUS     BUS_I2C2
#define PITOT_I2C_BUS           BUS_I2C2

#define USE_RANGEFINDER
#define RANGEFINDER_I2C_BUS     BUS_I2C1

// *************** UART *****************************
#define USE_VCP

#define USE_UART1
#define UART1_TX_PIN            PA9
#define UART1_RX_PIN            PA10

#define USE_UART2
#define UART2_TX_PIN            PD5
#define UART2_RX_PIN            PD6

#define USE_UART3
#define UART3_TX_PIN            PD8
#define UART3_RX_PIN            PD9

#define USE_UART4
#define UART4_TX_PIN            PB9
#define UART4_RX_PIN            PB8

#define USE_UART6
#define UART6_TX_PIN            PC6
#define UART6_RX_PIN            PC7

#define USE_UART7
#define UART7_TX_PIN            PE8
#define UART7_RX_PIN            PE7

#define USE_UART8
#define UART8_TX_PIN            PE1
#define UART8_RX_PIN            PE0

#define USE_SOFTSERIAL1
#define SOFTSERIAL_1_TX_PIN      PC6  //TX6 pad
#define SOFTSERIAL_1_RX_PIN      PC6  //TX6 pad

#define SERIAL_PORT_COUNT       9

#define DEFAULT_RX_TYPE         RX_TYPE_SERIAL
#define SERIALRX_PROVIDER       SERIALRX_CRSF
#define SERIALRX_UART           SERIAL_PORT_USART6

// *************** SDIO SD BLACKBOX*******************
#define USE_SDCARD
#define USE_SDCARD_SDIO
#define SDCARD_SDIO_DEVICE      SDIODEV_1
#define SDCARD_SDIO_4BIT

#define ENABLE_BLACKBOX_LOGGING_ON_SDCARD_BY_DEFAULT

// *************** ADC *****************************
#define USE_ADC
#define ADC_INSTANCE                ADC1

#define ADC_CHANNEL_1_PIN           PC0  //ADC123 VBAT1
#define ADC_CHANNEL_2_PIN           PC1  //ADC123 CURR1
#define ADC_CHANNEL_3_PIN           PC5  //ADC12  RSSI
#define ADC_CHANNEL_4_PIN           PC4  //ADC12  AirS
#define ADC_CHANNEL_5_PIN           PA4  //ADC12  VB2
#define ADC_CHANNEL_6_PIN           PA7  //ADC12  CU2

#define VBAT_ADC_CHANNEL            ADC_CHN_1
#define CURRENT_METER_ADC_CHANNEL   ADC_CHN_2
#define RSSI_ADC_CHANNEL            ADC_CHN_3
#define AIRSPEED_ADC_CHANNEL        ADC_CHN_4

// *************** PINIO ***************************
#define USE_PINIO
#define USE_PINIOBOX
#define PINIO1_PIN                  PD10  // VTX power switcher
#define PINIO2_PIN                  PD11  // 2xCamera switcher

// *************** LEDSTRIP ************************
#define USE_LED_STRIP
#define WS2811_PIN                  PA8

#define DEFAULT_FEATURES            (FEATURE_OSD | FEATURE_TELEMETRY | FEATURE_CURRENT_METER | FEATURE_VBAT | FEATURE_TX_PROF_SEL | FEATURE_BLACKBOX)
#define CURRENT_METER_SCALE         250

#define USE_SERIAL_4WAY_BLHELI_INTERFACE

#define TARGET_IO_PORTA (0xffff & ~(BIT(14) | BIT(13)))
#define TARGET_IO_PORTB 0xffff
#define TARGET_IO_PORTC 0xffff
#define TARGET_IO_PORTD 0xffff
#define TARGET_IO_PORTE 0xffff

#define MAX_PWM_OUTPUT_PORTS        15
#define USE_DSHOT
#define USE_ESC_SENSOR

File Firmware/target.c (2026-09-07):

/*
 * This file is part of INAV.
 *
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
 * You should have received a copy of the GNU General Public License
 * along with INAV.  If not, see <http://www.gnu.org/licenses/>.
 */

#include <stdint.h>

#include "platform.h"

#include "drivers/bus.h"
#include "drivers/io.h"
#include "drivers/pwm_mapping.h"
#include "drivers/timer.h"
#include "drivers/pinio.h"
#include "drivers/sensor.h"

BUSDEV_REGISTER_SPI_TAG(busdev_mpu6000,  DEVHW_MPU6000,  MPU6000_SPI_BUS,   MPU6000_CS_PIN,   NONE,   0,  DEVFLAGS_NONE,  IMU_MPU6000_ALIGN);
BUSDEV_REGISTER_SPI_TAG(busdev_icm42688, DEVHW_ICM42605, MPU6000_SPI_BUS,   MPU6000_CS_PIN,   NONE,   0,  DEVFLAGS_NONE,  IMU_MPU6000_ALIGN);
BUSDEV_REGISTER_SPI_TAG(busdev_icm20602, DEVHW_MPU6500,  MPU6500_SPI_BUS,   MPU6500_CS_PIN,   NONE,   1,  DEVFLAGS_NONE,  IMU_MPU6500_ALIGN);
BUSDEV_REGISTER_SPI_TAG(busdev_icm42605, DEVHW_ICM42605, ICM42605_SPI_BUS,  ICM42605_CS_PIN,  NONE,  2,  DEVFLAGS_NONE,  IMU_ICM42605_ALIGN);

timerHardware_t timerHardware[] = {
    DEF_TIM(TIM3, CH1, PB4, TIM_USE_OUTPUT_AUTO, 0, 0),   // S1
    DEF_TIM(TIM3, CH2, PB5, TIM_USE_OUTPUT_AUTO, 0, 1),   // S2

    DEF_TIM(TIM3, CH3, PB0, TIM_USE_OUTPUT_AUTO, 0, 2),   // S3  
    DEF_TIM(TIM3, CH4, PB1, TIM_USE_OUTPUT_AUTO, 0, 3),   // S4
    DEF_TIM(TIM1, CH1, PA8, TIM_USE_OUTPUT_AUTO, 0, 4),   // S5
    DEF_TIM(TIM4, CH3, PD14, TIM_USE_OUTPUT_AUTO, 0, 5),   // S6

    DEF_TIM(TIM4, CH4, PD15, TIM_USE_OUTPUT_AUTO, 0, 6),   // S7
    DEF_TIM(TIM8, CH1, PC6, TIM_USE_OUTPUT_AUTO, 0, 7),   // S8
    DEF_TIM(TIM8, CH2, PC7, TIM_USE_OUTPUT_AUTO, 0, 9),   // S9
    DEF_TIM(TIM8, CH4, PC9, TIM_USE_OUTPUT_AUTO, 0, 10),   // S10 

    DEF_TIM(TIM15,  CH1, PE5,  TIM_USE_LED, 0, 9),    // LED_2812
    DEF_TIM(TIM15,  CH2, PE6,  TIM_USE_LED, 0, 9),    // LED_2812
};

const int timerHardwareCount = sizeof(timerHardware) / sizeof(timerHardware[0]);

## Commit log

2026-08-13 Add hardware selection details to JOURNAL.md
    Document hardware selection for flight control project, including microcontroller, memory, sensors, and power supply.
2026-08-14 Correct dates and expand STM32 schematic details
    Updated journal entries with correct dates and added details about the STM32 schematic setup.
2026-08-14 Update JOURNAL.md with pin planning details
    Documented planning of pin functions using CubeMX for UARTs and peripherals.
2026-08-15 Update JOURNAL.md with power setup and pin mapping
    Documented power setup and pin mapping details, including USB C port and voltage conversion.
2026-08-15 Update JOURNAL.md with sensor setup details
    Documented sensor setup and buck converter correction.
2026-08-30 Update sensor configuration and add analog OSD
    Removed the magnetometer and added options for an external magnetometer and an airspeed sensor on the I2C bus. Introduced an analog OSD using the AT7456E with corresponding JST connectors.
2026-08-31 Update JOURNAL.md with schematic and layout details
    Finalized schematic and layout setup, corrected errors, and planned board layout.
2026-09-01 Update JOURNAL.md with PCB layout details
    Document PCB layout progress and time spent.
2026-09-01 Update JOURNAL.md with power layout entry
    Document power layout details and time spent.
2026-09-01 Add time spent entry to JOURNAL.md
    Documented total time spent on layout and power rail design.
2026-09-02 Revise PCB design for better efficiency and compactness
    Redesigned PCB layout for improved component placement and routing.
2026-09-02 Update image in README to new PCB design
2026-09-02 Update JOURNAL.md with redesign notes
    Added reflections on the redesign of the PCB layout and total time spent.
2026-09-04 Format BOM section with bold headings
2026-09-04 Update README with board cost details
    Added cost information for the board from JLCPCB.
2026-09-07 Update README with firmware flashing details
    Added firmware flashing instructions for the board.
2026-09-07 Update README with peripherals information
    Added peripherals section with wiring diagram and details.
2026-09-07 Format BOM section in README.md
2026-09-09 Update BOM section in README
    Removed detailed BOM list of components and added a reference to BOM.csv for component details.
2026-09-29 Change image in README
    Updated image in README from pcb6.png to 20260927_164700.jpg.

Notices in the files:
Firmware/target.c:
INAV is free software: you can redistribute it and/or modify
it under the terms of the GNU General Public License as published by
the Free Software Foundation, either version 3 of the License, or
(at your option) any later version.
